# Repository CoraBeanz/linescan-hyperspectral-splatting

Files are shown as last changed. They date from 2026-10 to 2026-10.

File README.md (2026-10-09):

<p align="center">
  Line-Scan Hyperspectral 3D Gaussian Splatting. An SO-101 robot arm holds a spectrograph whose scan line sweeps across a potted plant; behind the line the plant turns into Gaussians, and one Gaussian's stored spectrum is shown in a callout.
</p>

<h3 align="center">A homebuilt pushbroom spectrograph rides a robot arm, and the 3D Gaussian splat it trains stores a full 500–950 nm spectrum in every Gaussian instead of an RGB color.</h3>

<p align="center">
  
  
  
  
  
  
</p>

<p align="center">
  <a href="#how-it-works"><b>How it works</b></a> ·
  <a href="#the-rig"><b>The rig</b></a> ·
  <a href="#cad-model"><b>CAD model</b></a> ·
  <a href="#optical-path"><b>Optical path</b></a> ·
  <a href="#optiland-model"><b>Optiland model</b></a> ·
  <a href="#software"><b>Software</b></a> ·
  <a href="#reconstruction"><b>Reconstruction</b></a> ·
  <a href="#roadmap"><b>Roadmap</b></a> ·
  <a href="docs/parts_list_and_design.md"><b>Parts list</b></a>
</p>

## How it works

A hyperspectral camera records a whole spectrum at every pixel instead of three color channels, which shows things RGB can't, like the sharp rise in a leaf's reflectance just past red. This one is built from M12 board lenses, grating film and a Raspberry Pi camera sensor, for under $500 in optics and scanner parts.

| 1 · Pick a viewpoint | 2 · Sweep the slit | 3 · Train the splat |
|---|---|---|
| The SO-101 arm carries the scanner head to a pose and holds still. An RGB camera on the head reads an AprilTag board to get that pose. | A NEMA 8 stepper turns the scan mirror one microstep per frame. Each frame is one line of the object by its spectrum, and about 150 lines cover a 63 × 42 mm patch. | Every scan line is a training sample. A C++/CUDA renderer draws the splat through a line-camera model at that line's pose and compares it with the measured line. |

## The rig

<p align="center">
  Side view of the setup: the SO-101 arm holds the scanner head above a potted plant on an AprilTag board, a scan mirror sweeps a line across the plant, halogen lamps light it, and a Jetson Nano and an ESP32 sit on the table. An inset shows the parts inside the scanner head.
</p>

<table>
  <tr>
    <td width="42%" valign="top">
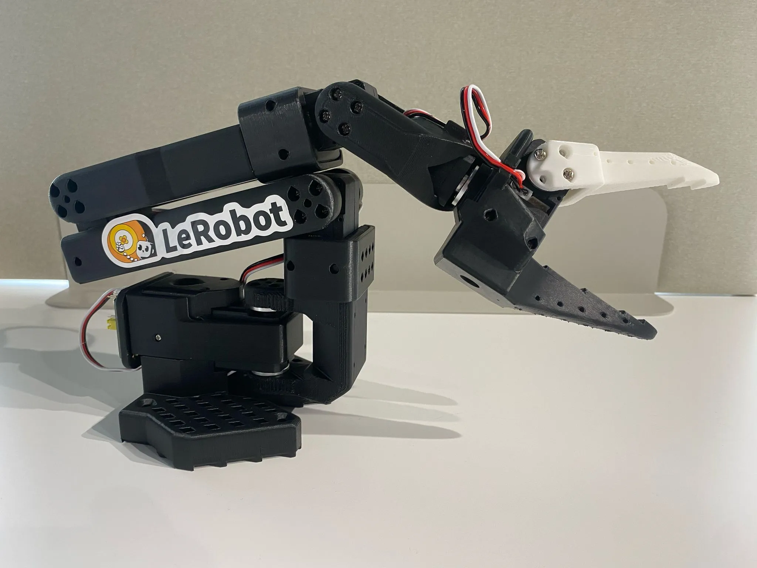
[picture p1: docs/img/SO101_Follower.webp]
Photo of an assembled SO-101 follower arm
      
      <br><sub>SO-101 follower arm. Photo: <a href="https://github.com/TheRobotStudio/SO-ARM100">TheRobotStudio/SO-ARM100</a>, Apache-2.0.</sub>
    </td>
    <td valign="top">

**Arm.** An [SO-101](https://huggingface.co/docs/lerobot/so101) follower from [LeRobot](https://github.com/huggingface/lerobot), with six STS3215 servos. It only sets the viewpoint, then holds still while the mirror scans.

**Scanner head.** The spectrograph below, plus a first-surface scan mirror on a 60 g NEMA 8 stepper. A TMC2209 driver runs it at 1/32 microstepping from an ESP32, which takes plain-text commands from the Jetson over USB serial.

**Pose.** An RGB camera on the head sees an AprilTag board under the object.

**Light.** Halogen lamps, because LEDs give almost nothing past 700 nm.

**Compute.** A Jetson Nano for capture, the calibration warp and the CUDA splat renderer.

  </td>
  </tr>
</table>

## CAD model

<p align="center">
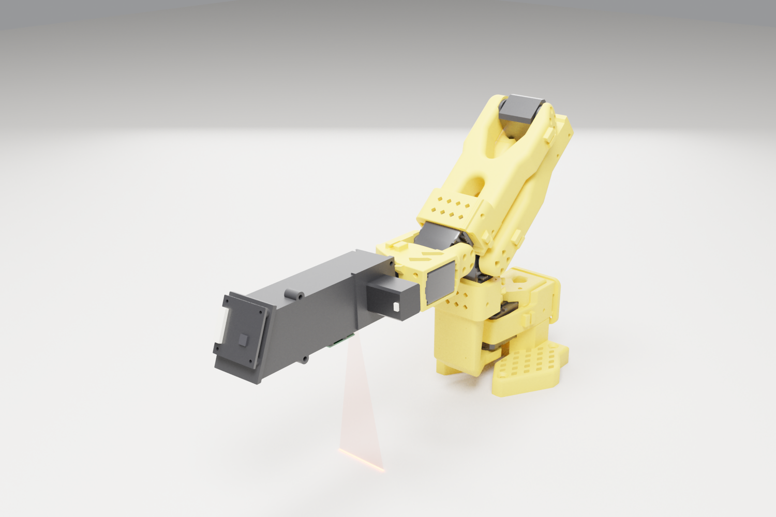
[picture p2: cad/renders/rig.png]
Render of the FreeCAD model: the SO-101 arm, folded, holds the black scanner head out over a table, and a faint red fan of light from the scan window draws a line on the table.
  
</p>

<table>
  <tr>
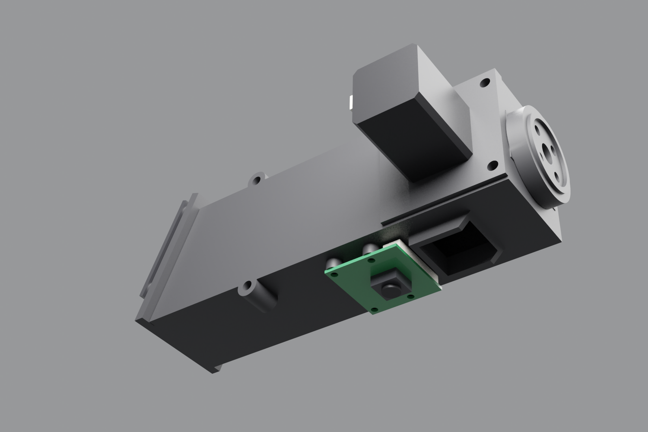
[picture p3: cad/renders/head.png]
The scanner head from below: the housing with its scan window and hood, the pose camera board, the NEMA 8 stepper on the lid and the round wrist puck.
    <td width="50%"></td>
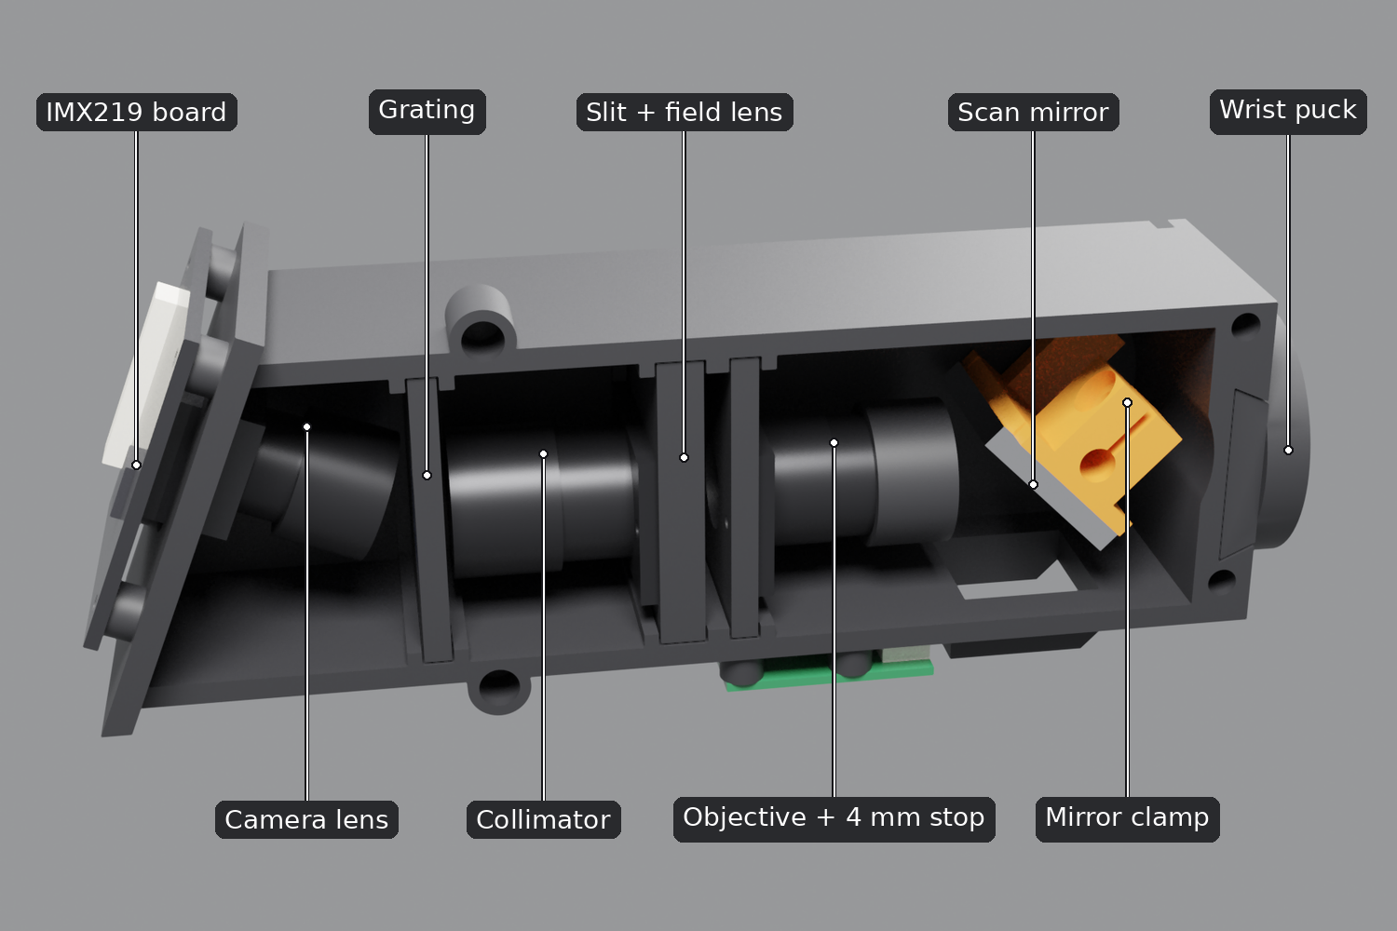
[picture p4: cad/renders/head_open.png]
The head with the lid and stepper hidden and the parts labelled: IMX219 board, camera lens, grating, collimator, slit and field lens, objective with its 4 mm stop, scan mirror on its clamp, and the wrist puck.
    <td width="50%"></td>
  </tr>
  <tr>
    <td><sub>The head from below: scan window and hood, pose camera, NEMA 8 stepper, wrist puck.</sub></td>
    <td><sub>Lid and stepper hidden to show the optical train.</sub></td>
  </tr>
</table>

The whole rig is a parametric [FreeCAD model](cad/). One script builds the SO-101 from its URDF, reads the optical spacings from the Optiland model, and wraps the optics in a printable PETG housing that slides onto a puck on the wrist-roll servo. It checks the parts for clashes, the mirror's full turn and the wrist's clearance, and works out the servo load: the 185 g head needs 74% of the shoulder servo's stall torque with the arm stretched out level, and 18% in the folded scanning pose above. The STLs and assembly steps are in [`cad/`](cad/).

## Optical path

<p align="center">
  Optical path, side view in the dispersion plane: light from one line of the object reflects off the scan mirror, passes a 500 nm long-pass filter and a 16 mm objective, focuses on a 50 micron slit with a field lens behind it, is collimated by a 25 mm lens, fanned out by a 500 lines per mm grating a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
</p>

A 16 mm f/4 objective images the object onto a 50 µm slit, so the instrument sees one line at a time. A field lens right behind the slit steers every point of that line toward the camera. A 25 mm lens, used backward, collimates the light, and a 500 lines/mm transmission grating fans it out by wavelength. A 12 mm f/2 lens, tilted 22° to the first diffraction order, refocuses the fan onto an IMX219 NoIR sensor, so each frame is one line of the object by its spectrum. A 500 nm long-pass filter in front keeps second-order light off the near-infrared end. Why each part is there: [final optical train](docs/parts_list_and_design.md#2-final-optical-train-config-c).

### What the camera sees

<p align="center">
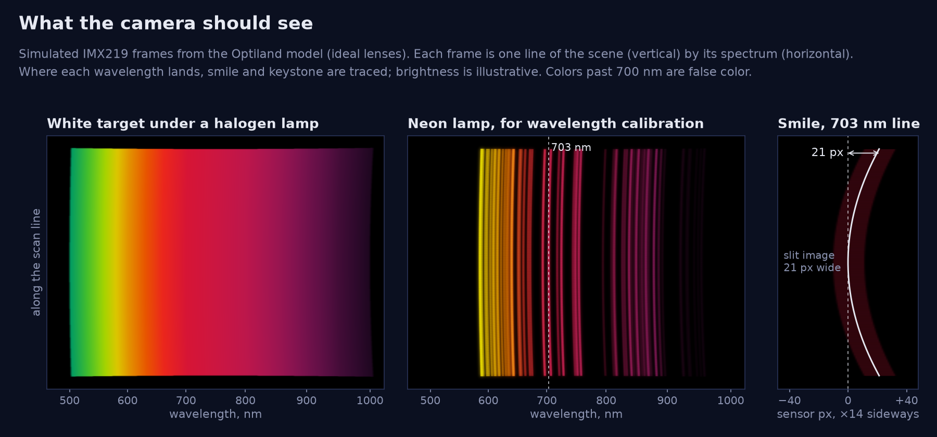
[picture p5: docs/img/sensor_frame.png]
Simulated IMX219 frames from the Optiland model: a white target under a halogen lamp shows a smooth band from green to near-infrared, a neon lamp shows curved emission lines, and a zoom shows the smile of the 703 nm neon line.
  
</p>

Each frame is the scan line (vertical) by its spectrum (horizontal), at about 5.8 px per nm. Spectral lines bow slightly across the frame (smile, up to about 33 px at the line ends) and the line length shifts a little with wavelength (keystone, about 11 px). Both get calibrated once with lamp lines and removed by a warp.

## Optiland model

[`optics/spectrograph_model.py`](optics/spectrograph_model.py) builds the whole train in [Optiland](https://github.com/HarrisonKramer/optiland) with ideal thin lenses and traces it. Tracing changed the design twice: the stock Pi NoIR lens was far too small to catch the collimated beam, and without a field lens most of the light from the ends of the line missed the camera lens.

<p align="center">
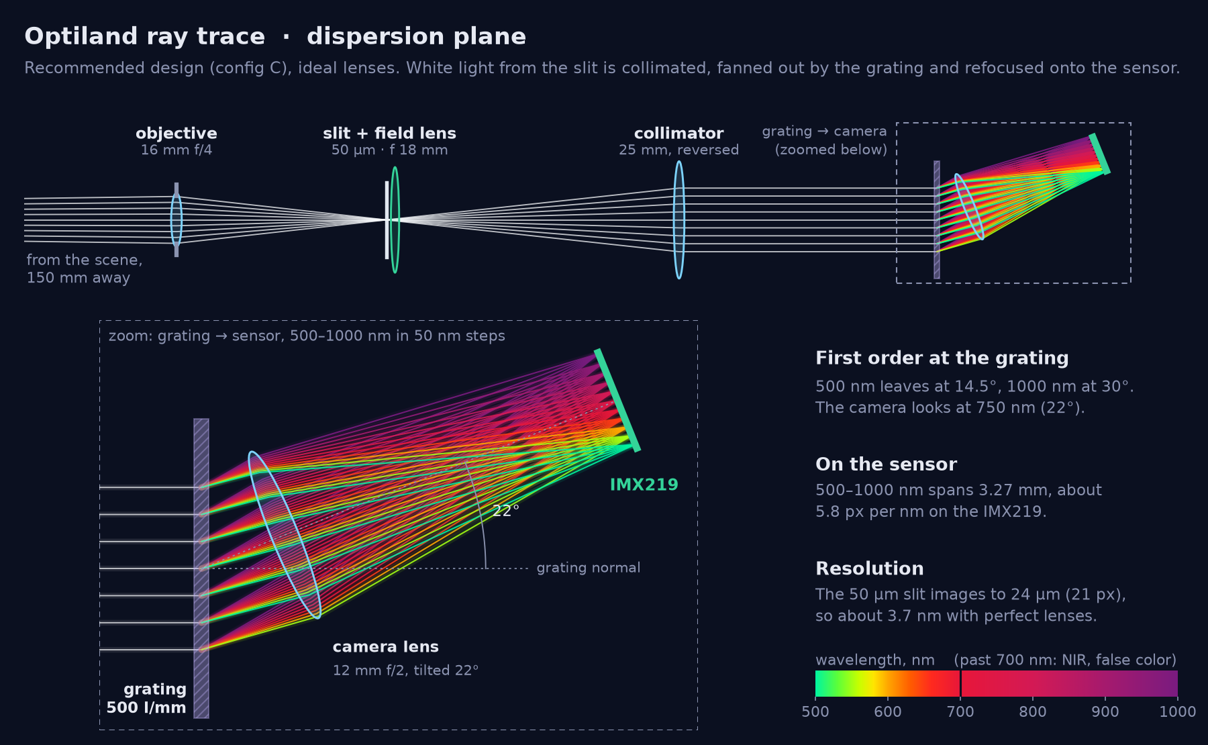
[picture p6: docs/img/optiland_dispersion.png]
Optiland ray trace of config C in the dispersion plane: white light from the slit is collimated, fanned out by the grating from 500 to 1000 nm and refocused onto the sensor by the camera lens tilted 22 degrees.
  
</p>

<p align="center">
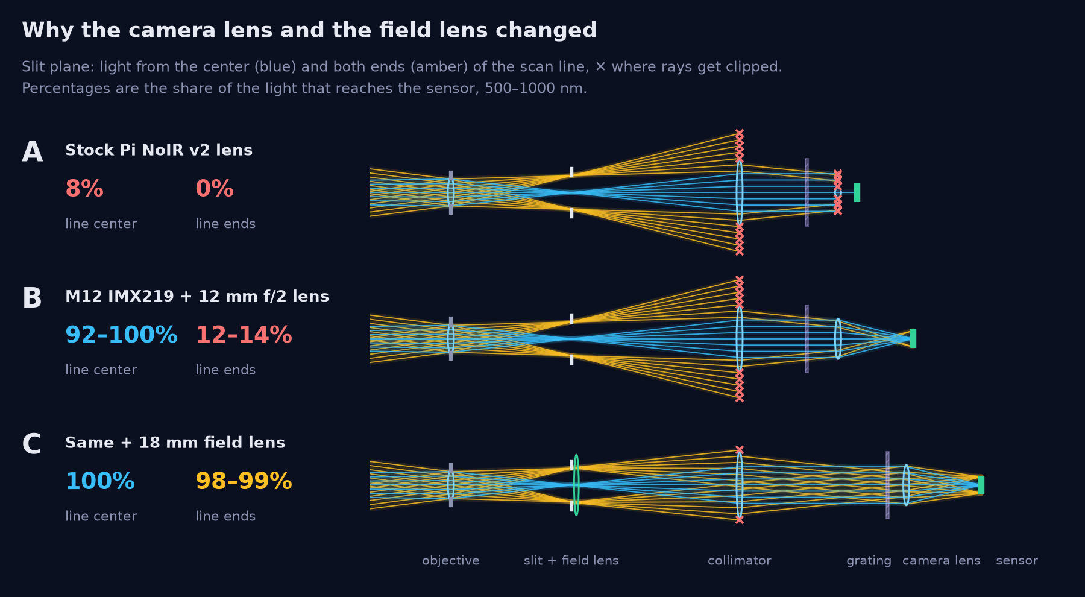
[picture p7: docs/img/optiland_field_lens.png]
Optiland traces of configs A, B and C in the slit plane. Light from the ends of the scan line gets clipped in A and B; with the field lens in C, 98 to 99 percent of it reaches the sensor.
  
</p>

| Config (ideal lenses) | Light at line center | Light at line ends | Dispersion | Spectral resolution | Pixels along the line |
|---|---|---|---|---|---|
| A: stock Pi NoIR v2 lens | 8% | 0% | 1.5 px/nm | 3.7 nm | 543 |
| B: M12 IMX219 + 12 mm f/2 lens | 92–100% | 12–14% | 5.8 px/nm | 3.7 nm | 2,143 |
| **C: B + 18 mm field lens** | **100%** | **98–99%** | **5.8 px/nm** | **4.1 nm** | **2,204** |

Resolution is geometric, with perfect lenses: the slit image's width over the dispersion. For A and B it is the paraxial estimate. For C it is traced through the grating, which widens the slit image 1.08× as the beam leaves at 22°, and the field lens adds 1.03×. The parts that were bought trace to 4.1 nm as [`cad/`](cad/README.md) builds the head, with the field lens curved side to the slit (config E); turned the other way it would be 5.4 nm (config D, [design notes](docs/parts_list_and_design.md#with-the-parts-that-were-bought-configs-d-and-e)). Real M12 lenses will likely land around 5–8 nm. More in the [modeling notes](docs/parts_list_and_design.md#5-modeling-notes-and-limits).

```bash
pip install optiland                   # tested with 0.6.2
python optics/spectrograph_model.py    # prints the table, writes optics/model_output/
python optics/readme_figures.py        # redraws the Optiland figures in docs/img/
```

Full output: [`optics/model_output/results.txt`](optics/model_output/results.txt) and the [ray layouts](optics/model_output/).

## Software

<p align="center">
  Block diagram of the code. The scan-mirror firmware on the ESP32 talks to the ROS 2 scan arm on the Jetson Nano over USB serial. The camera's frames go to the ROS 2 side during scans and to the calibration kit as lamp frames, and the calibration kit gives the ROS 2 side a wavelength map and a warp.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
</p>

The rig isn't built yet, so every module is written and tested against simulated hardware: the firmware on a simulated rig, the ROS 2 side on a fake servo bus and a simulated mirror, the calibration kit on lamp frames rendered through the Optiland model, and the splat on a synthetic scan with known poses. The [instrument simulator](sim/) ties them together: a digital twin of the whole rig that renders complete scan sessions, raw frames and logged poses, from a scene whose spectra and geometry are known. GitHub Actions runs each module's checks on every pull request that touches it.

| Module | What CI checks | Status |
|---|---|---|
| [Scan-mirror firmware](firmware/) | Unit tests on a simulated rig, again under AddressSanitizer and UndefinedBehaviorSanitizer, and the ESP32 build |  |
| [ROS 2 scan arm](ros2/) | `colcon build` and `colcon test` in a ROS 2 Humble container, up to a two-viewpoint scan on mock hardware |  |
| [Calibration kit](calibration/) | The self-test and unit tests on Python 3.10 and 3.13, and the Jetson's capture commands on Python 3.6 and numpy 1.13 against a stand-in camera |  |
| [Line-camera splat](splat/) | CPU build and unit tests, and a small synthetic scan trained end to end; the CUDA build with CUDA 13.4 for a desktop GPU (CI has no GPU, so the GPU tests skip there) |  |
| [Jetson Nano build](jetson/README.md) | The renderer and trainer built with the Nano's CUDA 10.2 and gcc 7.5 for sm_53, every kernel checked against the Nano's registers and shared memory, and the tests on arm64 Ubuntu 18.04 |  |
| [Splat viewer](viewer/) | The page's file reader, colour weights, spectra and WebGL2 image against the C++ renderer, then the page itself at a desktop and a phone size, in headless Chromium |  |
| [GitHub Pages site](https://corabeanz.github.io/linescan-hyperspectral-splatting/) | Builds the front page and the viewer, opens them in headless Chromium, and deploys them from `main` |  |
| [Instrument simulator](sim/) | The self-test, which scans a relief target, calibrates the simulated instrument and checks the reflectance against the truth, and the unit tests, on Python 3.10 with the oldest packages it allows and on 3.13 |  |
| [Virtual first light](pipeline/) | Nightly: a simulated scan through calibration, conversion, training, export and the viewer's reader, each hand-off checked against the simulator's truth |  |
| [CAD model](cad/) | Lint on the FreeCAD scripts |  |
| [PCBs](pcb/) | KiCad's ERC and DRC on the scan-mirror controller and hall-sensor boards, including the check that each board matches its schematic |  |
| [Optiland model](optics/) | Reruns the model and checks that its results, the CAD's as-built optics and the calibration kit's design map are current |  |
| README and docs | The diagrams match the scripts that draw them, and every relative link resolves |  |

Each module's README says how to build and test it locally, and its workflow in [`.github/workflows/`](.github/workflows/) runs the same commands.

### Scan-mirror firmware

<p align="center">
  Timing diagram of a stare scan. At each tick of a line clock, 33.3 ms apart at 30 frames per second, the ESP32 sends two step pulses 0.65 ms apart; the MOVING pin stays high until the mirror has been still for 3 ms, then the TRIG pin pulses and the line is reported ready. Each camera frame, a rolli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
</p>

An ESP32 runs the mirror from a 50 µs timer interrupt and keeps a line clock that follows the camera's frames. In a stare scan it steps the mirror at each tick, waits for it to settle, and holds it still through the frame; in a sweep scan it turns the mirror at a constant speed and reports its exact position at each tick. Every line, move and hall-sensor edge is stamped in ESP32 microseconds, so each camera frame can be matched to a mirror angle. Homing finds the middle of a hall sensor's window, which repeats to a microstep, and the TMC2209's current and microstepping are set over its UART, with a watchdog that stops the motor on a driver fault.

The Jetson talks to it in [plain-text lines over USB serial](firmware/PROTOCOL.md) rather than micro-ROS, as first planned: there's no agent to run, any serial monitor can drive it, and a ROS 2 node turns it into topics and services. Wiring, first power-up and a bench test with a logic analyser are in [`firmware/`](firmware/).

### ROS 2 scan arm

ROS 2 Humble runs in Docker on the Jetson Nano, since JetPack 4 is Ubuntu 18.04. A ros2_control driver runs the SO-101's STS3215 servos at 100 Hz. For each viewpoint in a plan, `scan_sweep` moves the arm, waits for it to stop, and asks the mirror bridge for a sweep. The bridge maps the ESP32's clock onto ROS time, so each line gets the arm's joint angles at the moment the mirror settled. Through the URDF, which takes the head's geometry from the CAD model, those give the head pose and the line-camera pose: one row per line in `lines.csv`. With mock servos and a simulated mirror the whole stack runs on any Linux machine with Docker, and Foxglove draws every scan line where it lands. The driver also stops the arm on a servo fault, a stall or an e-stop, and keeps the head off the table ([arm safety](ros2/README.md#arm-safety)). Setup on the Nano and first steps with the real arm: [`ros2/`](ros2/README.md).

### Calibration

<p align="center">
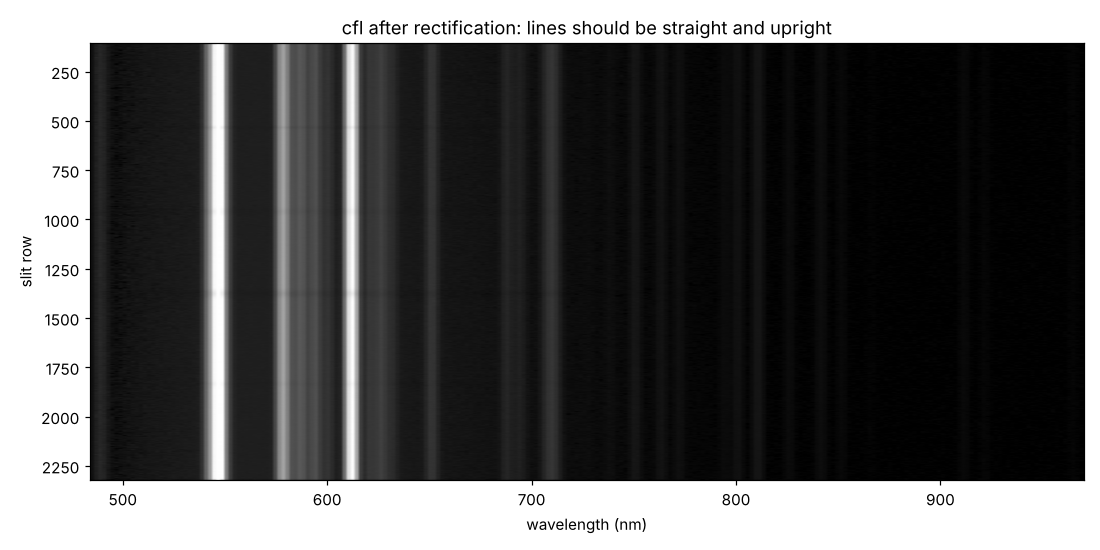
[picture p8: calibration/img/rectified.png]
A synthetic CFL frame after calibration: wavelength from 484 to 970 nm across, slit rows down; every lamp line is a straight vertical stripe.
  
  <br><sub>A synthetic CFL frame after calibration. On the sensor these lines bow by up to 35 px; here each one is a straight column at its own wavelength.</sub>
</p>

About ten minutes of lamp frames calibrate the spectrograph. A CFL bulb and a neon glow lamp give about 100 lines from 490 to 970 nm, a halogen lamp on PTFE gives the slit's ends and the spectral response, and a red laser pointer checks the result. The calibration kit, `hsical`, fits the wavelength of every pixel, the warp that straightens the bowed lines (smile) and evens out the slit's length across wavelengths (keystone), and the response that turns counts into radiance or reflectance, then writes a report with pass/fail checks. Its capture commands run on the Jetson's stock Python 3.6; the fitting runs on a PC. Before a scan, `hsical check` compares a quick CFL frame with the calibration and says whether anything has moved since.

Without the hardware, it is tested on sessions rendered through the Optiland model from a deliberately imperfect copy of the design: shifted on the sensor, with a denser grating, barrel distortion, dust on the slit, the sensor's colour mosaic and noise. At full resolution it recovers the truth to:

| Error against the truth | Result | Limit |
|---|---|---|
| Wavelength of every pixel, rms | 0.020 nm | 0.10 nm |
| Wavelength of every pixel, worst | 0.070 nm | 0.30 nm |
| Laser wavelength | 0.003 nm | 0.20 nm |
| Reflectance of a test scene, rms | 0.8% | 3% |

First light step by step, and how each fit works: [`calibration/`](calibration/).
Where the head's cameras and mirror really sit on the wrist, measured from one scan of a printed tag board: [`calibration/headcal/`](calibration/headcal/README.md).

### Instrument simulator

<p align="center">
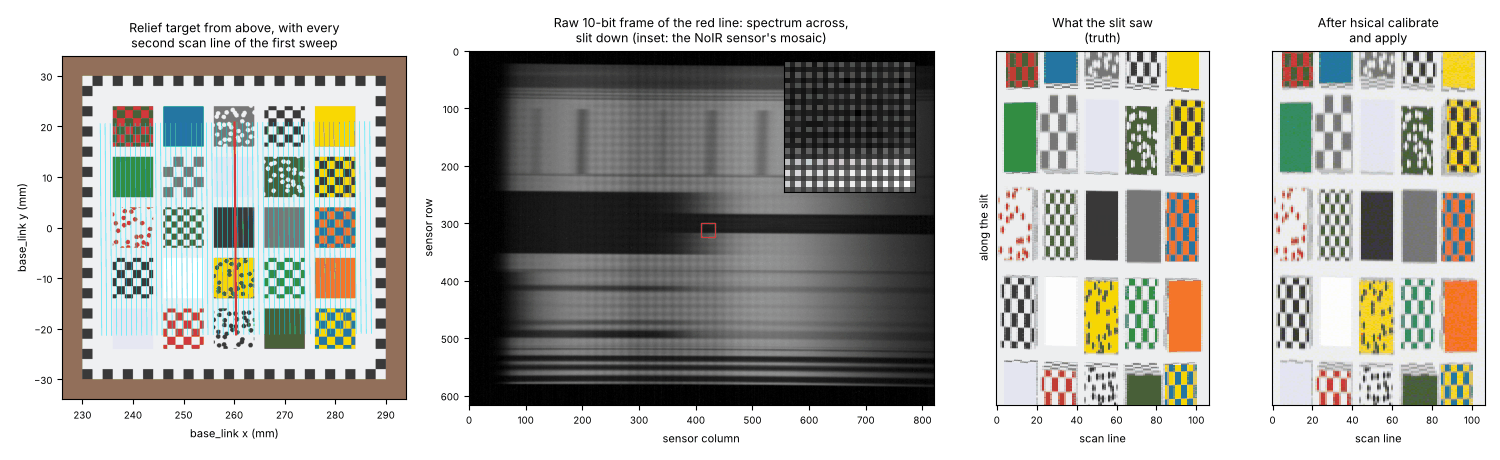
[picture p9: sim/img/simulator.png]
Four panels from the simulator. The relief target from above: a 5 by 5 block of coloured and patterned pillars inside a checker border, with the first sweep's scan lines drawn across it. A raw sensor frame of one line: a grey band of spectrum with dark absorption bars and horizontal stripes where t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
  
  <br><sub>The relief target with every second line of the first sweep, the raw frame of the red line, and the whole sweep as the slit really saw it next to what the calibration kit made of the raw frames.</sub>
</p>

The [simulator](sim/) is a digital twin of the whole scanner: the arm, the scan mirror, the objective and slit, the spectrograph and its camera. Given a scene with known spectra and a scan plan, it renders the raw frame of every scan line and writes a complete session in the rig's own format, with the arm's servo offsets, flex and encoder steps and the mirror's homing error in the log, as the real rig's will have them. Most of it is the repo's own code, imported rather than copied: the URDF's kinematics from the ROS 2 package, the synthetic spectrograph from the calibration kit, and the Optiland design map. Its self-test calibrates the simulated instrument, turns two sweeps of a relief target into reflectance and checks them against the truth: 1.6% RMS reflectance error, and the absorption bands of a rare-earth tile within 0.07 nm.

### On the Jetson Nano

The Nano is stuck on JetPack 4.6: Ubuntu 18.04, CUDA 10.2 and gcc 7. [`jetson/`](jetson/README.md) builds splat for its GPU in a container that uses JetPack's own CUDA, and builds the ROS 2 image in a way JetPack's old Docker can manage. A day-one script builds and tests both and times training on the GPU. From a PC, the same scripts build splat with the Nano's compilers, check that every kernel fits the Nano's registers and shared memory, and run the tests on arm64 Ubuntu 18.04. What training needs on the Nano, in memory and time per dataset, and the commands that measure it: [`splat/docs/nano_budget.md`](splat/docs/nano_budget.md).

## Reconstruction

Published hyperspectral splatting, such as [HyperGS](https://openaccess.thecvf.com/content/CVPR2025/papers/Thirgood_HyperGS_Hyperspectral_3D_Gaussian_Splatting_CVPR_2025_paper.pdf) and [DD-HGS](https://arxiv.org/abs/2505.21890), trains on full multi-view hyperspectral images. Here the splat trains straight from raw scan lines, through a model of the instrument itself.

- **Spectral Gaussians.** Each Gaussian keeps the usual position, shape and opacity, and stores a spectrum over 500–950 nm where a normal splat stores RGB.
- **A line camera, not a pinhole.** The slit only sees a thin fan of rays, and the mirror angle tilts that fan. For each scan line, the renderer draws the splat along that one fan and compares the resulting line of spectra with the measured line.
- **Poses get refined too.** The arm and the tag board give each viewpoint a pose, and the optimizer can adjust those poses along with the Gaussians, so small arm errors don't blur the result.
- **Calibrated input.** Neon and CFL lamp lines fix the wavelength scale, the warp removes smile and keystone, and a white PTFE reference turns counts into reflectance.

Splatting through a non-pinhole camera has precedent in satellite imagery ([RPC-GS](https://arxiv.org/abs/2606.06690)), and close-range pushbroom cameras have been calibrated for plant phenotyping ([Behmann et al. 2015](https://doi.org/10.1016/j.isprsjprs.2015.05.010)). This project puts the two together on hobby hardware.

### Training on a synthetic scan

The renderer and trainer in [`splat/`](splat/) are C++17, with a CUDA rasterizer written for the Nano's CUDA 10.2 and a CPU reference that the tests hold it to. Until there are real scans, they train on a synthetic one: a board with paint patches, a hidden word that only shows past 740 nm, a leaf-green ball and an orange box, scanned through the head's mirror geometry from the CAD model. Each sweep's head pose is off by about 1 mm and 0.3° per axis, as the arm's will be.

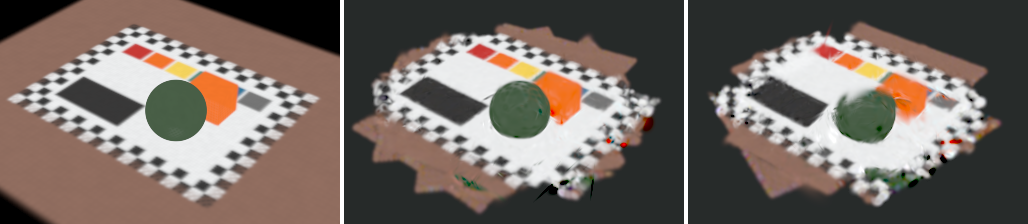
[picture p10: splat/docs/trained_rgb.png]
Three views of the scene from the overview camera: the true scene, a splat trained from 16 sweeps that matches it closely, and one trained from 8 sweeps, where the ball smears into the board and the checker border doubles.


The true scene (left), and splats trained from 16 sweeps (middle) and from 8 (right). From 16 sweeps the trainer cuts the pose error from 10.9 px to 0.97 px at 256 px per line, which lines the sweeps up to about 0.15 mm on the board, and it renders the measured lines down to their noise. That takes 16 s on a desktop RTX 4070 SUPER, or under two minutes on a 4-core CPU. From 8 sweeps the ball and the box are seen from too few directions and get painted onto the board, so the rig will scan many sweeps from all around. The model, the CUDA passes and more results are in [`splat/`](splat/).

### In the browser

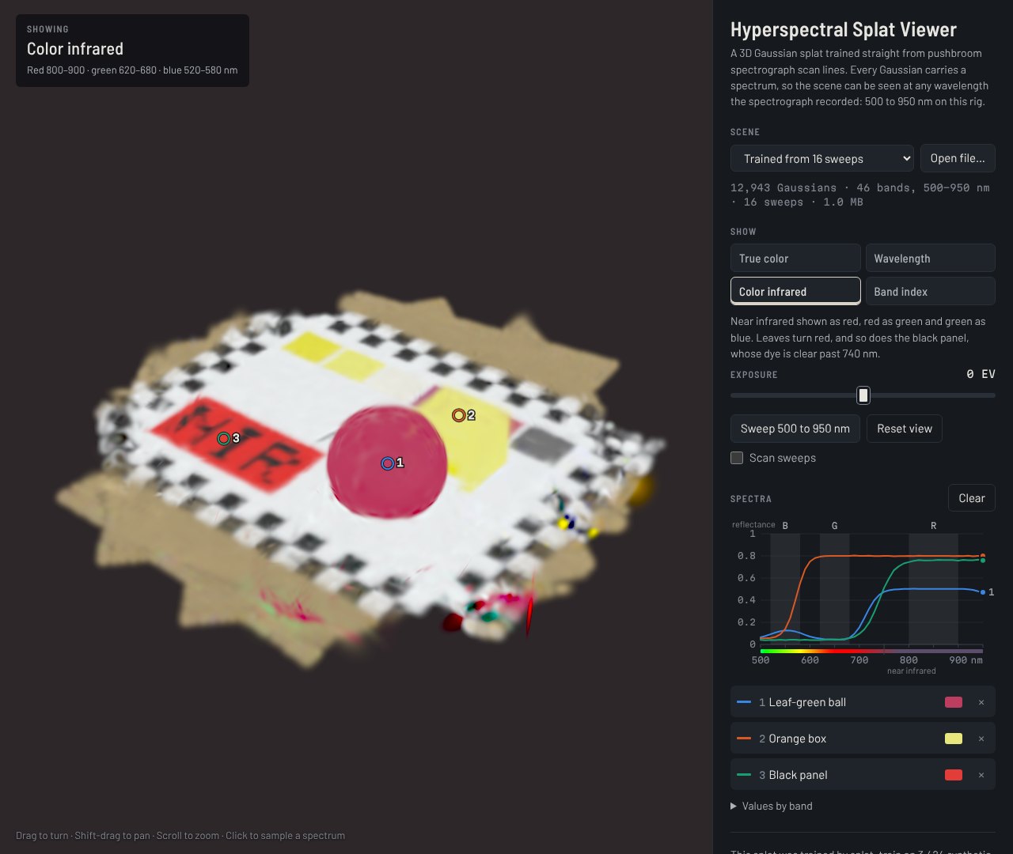
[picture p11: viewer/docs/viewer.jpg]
The viewer in color infrared: the splat trained from 16 synthetic sweeps, where the green ball and the black panel's hidden word NIR show red, beside the controls and a chart of the spectra sampled at the ball, the box and the panel.


Every Gaussian carries a spectrum, so the [viewer](viewer/) can draw a trained splat at any single wavelength, in true color, in color infrared, or as a band index such as NDVI, and it plots the full spectrum of any point you click. Above, in color infrared, the ball's leaf spectrum and the black panel's dye both rise past 700 nm, so both turn red and the hidden word shows. It is plain HTML, JavaScript and WebGL2 with no build step, and its tests check it against the C++ renderer. **[Open it in your browser](https://corabeanz.github.io/linescan-hyperspectral-splatting/viewer/)**, on GitHub Pages.

It also shows what each part of the scene is made of: [`splat_materials`](splat/README.md#material-maps) labels every Gaussian by spectral angle against a library of spectra, clusters them and unmixes them, and on the trained splat 97% of the map's pixels get the right material.

## Roadmap

- [x] First-order optical design and Optiland model (configs A, B, C, and D and E with the parts bought)
- [x] [FreeCAD model](cad/) of the arm and scanner head, with printable housing, optics carriers and wrist mount
- [x] [Software](#software), tested in CI against simulated hardware: scan-mirror firmware, ROS 2 scan arm, calibration kit, line-camera splat renderer and trainer, browser viewer, the Jetson Nano build and an instrument simulator
- [ ] **Bench spectrometer:** slit, field lens, collimator, grating and camera aimed at neon and CFL lamps; fit the wavelength map and the smile/keystone warp with the [calibration kit](calibration/)
- [ ] **Line imager:** add the objective, focus it on a printed target, measure the line on a knife edge
- [ ] **Scanner:** add the mirror and stepper, scan a color card, assemble the datacube on the Jetson (first CUDA kernel: warp + bin)
- [ ] **3D:** arm viewpoints and AprilTag poses, then the first splat trained on real scans

Details for each step are in the [build order](docs/parts_list_and_design.md#4-build-order).

## Stack

| Layer | Built with |
|---|---|
| **Optics** | Python and [Optiland](https://github.com/HarrisonKramer/optiland): ideal-lens model now, catalog lenses next |
| **CAD** | [FreeCAD](https://www.freecad.org/), scripted in Python around the SO-101's URDF |
| **Firmware** | C++ on an ESP32 (Arduino core, PlatformIO) driving a TMC2209, with Unity tests on a simulated rig |
| **Robotics** | ROS 2 Humble in Docker on the Jetson Nano: a ros2_control driver for the STS3215 servos, the URDF and the scan sweeps |
| **Capture and calibration** | Python, numpy and scipy; raw 10-bit frames from the IMX219 NoIR on the Jetson Nano's CSI port, through V4L2 |
| **Reconstruction** | C++17 and CUDA: line-camera Gaussian splat renderer and trainer for the Jetson Nano |
| **Viewer** | Plain HTML, JavaScript and WebGL2, tested in headless Chromium with Playwright |
| **Simulation** | Python and numpy, reusing the calibration kit's and the ROS 2 packages' own code |
| **CI** | GitHub Actions, a workflow per module |

## Repo map

```
docs/
├── parts_list_and_design.md   parts with vendors and prices, first-order design, build order
├── optical_train_v2.svg       optical train drawing (v1 kept alongside)
├── img/                       README figures; img/src/ holds the scripts that draw the SVGs
└── site/                      the GitHub Pages front page, and the script that builds the site
optics/
├── spectrograph_model.py      Optiland model of the spectrograph, configs A–E
├── readme_figures.py          traces the model and renders the Optiland figures
└── model_output/              results.txt and ray layouts
cad/
├── so101_hsi_rig.FCStd        FreeCAD assembly: SO-101 arm and scanner head
├── build_rig.py               builds it, checks clearances and servo load, exports
└── stl/, step/, renders/      printable parts, the head as STEP, images
firmware/
├── lib/scanmirror/            step generator, line clock, commands, homing: plain C++
├── src/main.cpp               the ESP32 glue
├── test/                      Unity tests on a simulated rig
└── PROTOCOL.md                the serial protocol
ros2/
├── so101_scan_*/              ROS 2 Humble packages: driver, URDF, bringup, sweeps, messages
└── docker/, udev/             the container for the Jetson Nano, stable device names
calibration/
├── hsical/                    capture, calibration, reports: python -m hsical
└── tests/                     pytest on synthetic sessions
splat/
├── include/, src/             line-camera renderer (CPU and CUDA) and trainer
├── tools/                     splat_synth, splat_train, splat_render, splat_export
└── tests/                     unit tests; the CUDA ones skip without a GPU
viewer/
├── index.html, js/            the browser viewer: WebGL2, no build step
├── data/                      two splats from the synthetic scan
└── test/                      checks against the C++ renderer, run in headless Chromium
sim/
├── hsisim/                    the instrument simulator: python -m hsisim
└── tests/                     pytest, up to a scan calibrated end to end
jetson/
├── build_all.sh, splat.sh     the Nano's day-one build, splat in its container
├── ros.sh                     the ROS 2 image on JetPack 4.6's Docker
└── check.sh                   the same builds from a PC, with the Nano's compilers
.github/workflows/             CI, a workflow per module
```

## Background reading

- Kerbl et al., [3D Gaussian Splatting for Real-Time Radiance Field Rendering](https://repo-sam.inria.fr/fungraph/3d-gaussian-splatting/), ACM TOG (SIGGRAPH) 2023. [arXiv:2308.04079](https://arxiv.org/abs/2308.04079)
- Thirgood et al., [HyperGS: Hyperspectral 3D Gaussian Splatting](https://openaccess.thecvf.com/content/CVPR2025/papers/Thirgood_HyperGS_Hyperspectral_3D_Gaussian_Splatting_CVPR_2025_paper.pdf), CVPR 2025
- Narayanan et al., [Diffusion-Denoised Hyperspectral Gaussian Splatting](https://arxiv.org/abs/2505.21890) (first posted as *Hyperspectral Gaussian Splatting*), arXiv 2025
- Wagner et al., [RPC-GS: Gaussian Splatting with native RPC Rendering for Satellite Imagery](https://arxiv.org/abs/2606.06690), arXiv 2026
- Behmann et al., [Calibration of hyperspectral close-range pushbroom cameras for plant phenotyping](https://doi.org/10.1016/j.isprsjprs.2015.05.010), ISPRS Journal of Photogrammetry and Remote Sensing 106, 2015

## Credits

- SO-101 photo: [TheRobotStudio/SO-ARM100](https://github.com/TheRobotStudio/SO-ARM100) (`media/SO101_Follower.webp`), used unmodified under the Apache License 2.0; a copy of the license is in [`docs/img/SO-ARM100_LICENSE.txt`](docs/img/SO-ARM100_LICENSE.txt). The SO-101 is designed by The Robot Studio in collaboration with Hugging Face.
- SO-101 URDF and meshes in the CAD model: [TheRobotStudio/SO-ARM100](https://github.com/TheRobotStudio/SO-ARM100) (`Simulation/SO101`), Apache License 2.0.
- Ray tracing: [Optiland](https://github.com/HarrisonKramer/optiland) (MIT).

## License

The code, the CAD model and the docs are under the [MIT License](LICENSE). The SO-101's URDF and meshes (and their decimated copies in the CAD model) and the SO-101 photo are TheRobotStudio's, under the Apache License 2.0, as listed in [Credits](#credits).

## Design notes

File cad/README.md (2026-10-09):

# CAD: the SO-101 with the scanner head

<p align="center">
  Render of the SO-101 arm holding the black scanner head over a table, with a red fan of light from the scan window drawing a line on the table.
</p>

A parametric FreeCAD model of the whole rig: the SO-101 follower arm, the spectrograph head with every bought part in place, the 3D-printed housing that holds them on the optical axis of [layout E](../optics/spectrograph_model.py) (the optics model of the parts that were bought), and a puck that bolts the head to the wrist-roll servo where the gripper used to be. A printed tray holds the scan-mirror controller board from [`pcb/`](../pcb/README.md) on the table behind the arm. One script builds it from a spreadsheet of numbers, checks it, and exports the STLs to print.

<table>
  <tr>
    <td width="50%">The head from below: scan window with its hood, pose camera board, stepper on the lid, and the round wrist puck.</td>
    <td width="50%">The head with the lid and stepper hidden and the parts labelled: scan mirror on its clamp, objective, slit and field lens, collimator, grating, tilted camera lens and the IMX219 board.</td>
  </tr>
  <tr>
    <td><sub>From below: scan window and hood, pose camera, stepper on the lid, wrist puck.</sub></td>
    <td><sub>Lid and stepper hidden.</sub></td>
  </tr>
</table>

## At a glance

- **Head:** 187 g and 64 × 53 × 136 mm, wrist puck included. The NEMA 8 stepper is 60 g of that.
- **Printed:** nine parts on the head, about 68 g of PETG, plus the controller tray (30 g), an optional bench mount and a spare stop washer.
- **Checks:** no parts overlap. The mirror turns a full circle with at least 0.5 mm to spare. The head clears the wrist at every roll angle (1.4 mm closest) and through ±95° of wrist flex.
- **Watch out:** with the arm stretched out level, the shoulder servo has to hold 1.21 N·m, which is 75% of its stall torque. The stock gripper needs 0.86 N·m there. The scanning pose in the render needs only 0.30 N·m. See [Arm load](#arm-load).

## Files

```
cad/
├── so101_hsi_rig.FCStd     the assembly, driven by its Params spreadsheet
├── build_rig.py            builds the .FCStd from scratch, runs the checks, writes everything below
├── build_report.json       mass budget, servo torques, clearances, optical stations
├── stl/                    printed parts, already turned to their print orientation
├── step/hsi_head.step      the head with every part, for other CAD tools
├── optics_check.py         traces the as-built spacings with the Optiland model
├── optics_as_built.txt     its output
├── renders/                the images on this page
├── render/                 Blender render script and the labelling step
├── rig/                    the model: parameters, printed parts, bought parts, arm, statics
└── vendor/so101/           SO-101 URDF and a script that downloads its meshes
```

## How the head works

The head has its own frame: the origin is on the face of the wrist-roll horn, +Z points out along the roll axis, +Y faces the scene, and X runs along the slit and the mirror shaft.

**Light path.** Light comes in through the scan window on the +Y face and hits the mirror at 45°. It then goes through the filter cap (a 495 nm long-pass disc, then a thin washer whose 4 mm hole is the stop), the objective, the slit with the field lens right behind it, curved side first, the reversed collimator and the grating film. The camera lens, tilted 22°, focuses it onto the IMX219.

**Mount.** The wrist puck replaces the gripper on the wrist-roll horn. A dovetail rail on the puck runs along X, and the slot in the housing floor is open on the −X side, so the housing slides onto the rail from there until it stops against the closed end. The lid closes the −X side and the end of the slot with it, so the lid screws are what hold the head on.

**Optics carriers.** The objective carrier, slit block and grating carrier are plates that slide into rib slots from the open side. That lets you build and align the optics before the lid goes on. The bench puck has the same rail on a 50 × 40 mm plate with a 1/4"-20 nut, so the head can sit on a tripod or the optics table for the bench steps in the [build order](../docs/parts_list_and_design.md#4-build-order).

**Scan mirror.** A printed clamp grips the stepper's 4 mm shaft with an M3 pinch screw and holds the mirror on a flat pad parallel to the shaft. The pad is drawn for a 20 × 20 mm piece cut from a 3 mm front-surface mirror sheet, and notches in its edges mark where the mirror's ends go so it sits centred on the optical axis. Along the shaft the piece can be anything from 20 to 25 mm. Across the shaft keep it at 20 mm or a little under, because its corners pass 0.9 mm from the housing as it turns. For thinner glass, set `mirror_t` and rebuild, or glue the mirror onto a printed shim that makes up the difference to 3 mm. A 5 × 1.6 mm magnet in the clamp's tab passes an A3144 hall sensor in the +X wall when the mirror is turned 40° back from its 45° working angle, which gives each scan a home position. The sensor's leads leave the bottom of its body, bend out through a slot under its pocket, and pass through the [hall breakout](../pcb/README.md#hall-sensor-breakout), which is screwed flat on the outside with one M2 × 5.

**Camera.** The B0152 board sits outside the end wall on four standoffs. The CIL122 goes in the board's own M12 holder, which reaches through a 21 mm hole in the wall. The hole is sized from `brd_holder_w` so a square holder passes at any angle. Turn the board so the sensor's long side runs across the slit, since that is the axis the spectrum spreads along. Black tape around the board edge keeps light out of the end.

**Pose camera.** The Pi NoIR v2 sits on four standoffs on the +Y face next to the scan window, looking at the scene.

## Parts

### Printed

Print the housing, lid and carriers in black PETG. PETG holds up to the stepper's heat, which PLA may not, and black keeps stray light down. The STLs are already turned to the orientation below.

| Part | File | How to print | Mass |
|---|---|---|---|
| Housing | [`housing.stl`](stl/housing.stl) | Floor (dovetail side) on the bed, camera end up. 0.2 mm layers, 3 perimeters, 20% gyroid, supports only under the camera flange | 37 g |
| Lid | [`lid.stl`](stl/lid.stl) | Inner (flat) face on the bed. 4 perimeters around the motor holes | 13 g |
| Mirror clamp | [`mirror_clamp.stl`](stl/mirror_clamp.stl) | Mirror pad face down. 0.15 mm layers, 100% infill | 2 g |
| Wrist puck | [`wrist_puck.stl`](stl/wrist_puck.stl) | Horn side down (it bridges the 20 mm horn recess). 100% infill | 5 g |
| Objective carrier | [`objective_carrier.stl`](stl/objective_carrier.stl) | Flat | 2 g |
| Slit block | [`slit_block.stl`](stl/slit_block.stl) | Back face down so the blade recess prints flat. 0.12 mm layers | 4 g |
| Grating carrier | [`grating_carrier.stl`](stl/grating_carrier.stl) | Flat, film recess up | 2 g |
| Filter cap | [`filter_cap.stl`](stl/filter_cap.stl) | Lip face down. Check that the sleeve is a snug push fit on the objective | 1 g |
| Stop washer, 4 mm | [`stop_washer.stl`](stl/stop_washer.stl) | Flat, 0.2 mm layers. Clear any stringing from the hole, since its edge is the stop | 0.1 g |
| Stop washer, 5 mm (optional) | [`stop_washer_5mm.stl`](stl/stop_washer_5mm.stl) | As the 4 mm one. Swap it in at first light to compare: see [Optics as built](#optics-as-built) | 0.1 g |
| Bench puck (optional) | [`bench_puck.stl`](stl/bench_puck.stl) | Flat side down. A 1/4"-20 hex nut presses in from below | 19 g |
| Controller tray | [`controller_tray.stl`](stl/controller_tray.stl) | Floor on the bed. 3 perimeters, 20% infill. It stays on the table, so PLA is fine: see [Controller tray](#controller-tray) | 30 g |

### Bought

| Part | In the model |
|---|---|
| Objective: Commonlands CIL161, 15.6 mm, stopped to f/3.9 by the 4 mm washer | barrel size estimated |
| Collimator: Arducam LN016, 25 mm, used backwards | size from the listing, back focus estimated |
| Camera lens: Commonlands CIL122, 12 mm f/2 | barrel size estimated |
| Camera: Arducam B0152 IMX219 NoIR, M12 mount | 36 × 36 mm from the listing; holes, thickness and holder estimated |
| 2× M12 holder, uxcell, 20 mm screw spacing (objective, collimator), each cut down to 10 mm: see [Assembly](#assembly) | 24 × 17 × 14 mm from the listing; ear thickness estimated |
| Field lens: Edmund #49-840, 12.7 mm plano-convex, f = 15 mm, uncoated | datasheet |
| Slit: two 20 mm pieces of a 9 mm snap-off blade, set 50 µm apart with a feeler gauge | single-edge blades (38 × 19 mm) don't fit inside the head |
| Grating: 15 × 15 mm piece of 500 l/mm film, grooves along X | |
| Long-pass filter: Edmund #54-652, SCHOTT GG-495, Ø12.5 × 3 mm | listing. The cap's seat takes the ±0.38 mm diameter tolerance |
| Scan mirror: 20 × 20 mm piece cut from a RUEHALF 100 × 100 × 3 mm front-surface mirror | thickness from the listing |
| Stepper: StepperOnline 8HS11-0204S, NEMA 8, 1.8°, 0.2 A | size, shaft and holes from the listing; boss and thread depth estimated |
| A3144 hall sensor and a 5 × 1.6 mm magnet, magnetized through its thickness | measured |
| Hall breakout from [`pcb/`](../pcb/README.md#hall-sensor-breakout), 14 × 12.4 × 0.8 mm, with its 3-wire cable soldered in | outline, holes and lead positions from `pcb/` |
| Pose camera: Pi NoIR v2 (owned) | Raspberry Pi drawing |

### Hardware

| Qty | Part | Where |
|---|---|---|
| 4 | M3 × 6 | puck to the servo horn |
| 4 | M2 × 4 | stepper to the lid, from inside (the heads sit flush) |
| 2 + 2 + 2 | M3 × 35, M3 washers and M3 nuts | from the counterbores on the +X face, through the floor and the lid, nutted on the lid's motor pad |
| 2 + 2 | M3 × 8 and M3 × 6 heat-set inserts (Pofsnnx: 5.0 mm knurl, 4.5 mm holes) | lid ears to the housing |
| 1 + 1 | M3 × 8 and M3 nut | mirror clamp pinch screw |
| 8 + 8 | M2 × 5 and M2 × 4 heat-set inserts (Pofsnnx: 3.0 mm knurl, 2.85 mm holes) | camera board (4) and pose camera (4) |
| 2 | M2 × 5 | objective's M12 holder to its carrier, self-tapping into the printed pilot holes |
| 2 | M2 × 5 | collimator's M12 holder to the back of the slit block, self-tapping (3 mm of thread in the block) |
| 1 | M2 × 5 | hall breakout to the +X wall, self-tapping (2.5 mm of thread in the wall) |
| 4 + 4 | M3 × 6 and M3 heat-set inserts | controller board to its tray |
| 2 + 2 | 1/4"-20 or M6 screws, to suit the table, and washers | tray to the optical table |

Plus CA glue for the magnet, mirror and slit blades, and Kapton tape for the grating film. The [NEMA 17 build](#the-nema-17-option) holds its motor with two M3 × 6 instead, and the long bolts thread into the motor rather than into nuts.

## Measure these first

These numbers came from estimates or listings, not datasheets. Check them when the parts arrive, before printing the part they affect. All of them are cells in the Params sheet; the estimates are marked `est`.

| Value | Assumed | Affects |
|---|---|---|
| B0152 hole spacing (`brd_hole` along X, `brd_hole_y` along the dispersion) | 29 mm square | camera standoffs on the housing |
| B0152 lens holder size (`brd_holder_h`, `brd_holder_w`) | 10 mm tall, 14 mm square | camera opening in the end wall |
| B0152 sensor above the PCB (`sensor_above_pcb`) and PCB thickness (`brd_t`) | 1 mm, 1.6 mm | where the end wall sits so the sensor is in focus; camera screw length |
| CIL161 barrel (`obj_od`, `obj_len`), on the M12ANIR version | Ø14 × 18.5 mm | filter cap fit, objective position, and where the stop washer sits: 8.5 mm ahead of the lens's principal plane as drawn, 8.1 mm in layout E |
| CIL122 barrel (`cam_od`, `cam_len`), on the M12ANIR version | Ø15 × 19 mm | how close the camera lens can get to the grating |
| LN016 length (`coll_len`) | 21 mm | grating carrier position |
| Lens back focal lengths (`*_bfl`) | 5–6 mm | carrier positions. Turning a lens in its M12 thread takes up a millimetre or two |
| LN016 back focus (`coll_bfl`): rear of the barrel to the sharp image of a distant lamp | 6.0 mm; a sibling Arducam 25 mm lens lists 5.2 | slit block thickness, which puts the collimator where it focuses on the slit |
| CIL122 aperture: its spec table says f/2.0, the text on the same page f/2.4 | f/2.0, a 6 mm pupil | not the CAD. At f/2.4 (5 mm) the ends of the band lose a little more light; set `d_cam` to 5 in [`spectrograph_model.py`](../optics/spectrograph_model.py) and rerun `optics_check.py` to see how much |
| Lens thread lengths (`obj_thread`, `coll_thread`): rear end to where the barrel widens | 9 mm | where to cut the M12 holders, see [Assembly](#assembly) |
| M12 holder ear thickness (`h12_ear_t`) | 2 mm | holder screw length: M2 × 5 leaves 3 mm of thread in the carrier |
| Snap-off blade thickness (`blade_t`) | 0.38 mm | depth of the blade recess in the slit block |
| Stepper pilot boss (`mot_boss_d`, `mot_boss_h`) | Ø15 × 1.5 mm | the pocket in the lid it sits in; the motor has to sit flat on the pad |
| Stepper thread depth (`mot_hole_depth`) | 2.5 mm | the M2 × 4 screws reach 2.2 mm into it. M2 × 5 reach 3.2 mm, so use them only if the holes are that deep, or file 1 mm off them |

## Assembly

1. Cut two of the uxcell M12 holders down to 10 mm, the lens thread plus 1 mm. Cut from the end the lens screws into, not the ear end, and square the cut on sandpaper. A lens screwed in until its barrel stops against the cut end then has its rear end 1 mm inside the holder, where the model puts it. If a lens's thread isn't 9 mm, cut its holder to the thread plus 1 mm; with 13 mm of thread or more, leave the holder whole. Then score and snap a 20 × 20 mm piece from the mirror sheet, scoring the bare back so the coated face isn't scratched.
2. Press in the heat-set inserts: two M3 in the lid bosses on the housing, four M2 in the camera standoffs and four M2 in the pose-camera standoffs.
3. Build the optics on their carriers. The objective's holder screws to the objective carrier. Drop the long-pass disc into the filter cap and the 4 mm stop washer in on top of it, then push the cap onto the front of the lens until the lens presses them together. In the slit block, the field lens drops into its pocket from the front, curved side up toward the blades, and its flat face sits on the ledge at the bottom of the pocket (a dot of glue on its rim stops it rattling). Turned the other way it would make the slit look 1.35× as wide, and the resolution would drop from 4.1 to 5.4 nm. The two blade pieces go in the recess over it with the 0.05 mm feeler blade setting the gap, and the collimator's holder screws to the back. Tape the grating film into its carrier with the grooves along X. Slide the three carriers into their slots.
4. Fit the camera board on the end wall and the pose camera on the +Y face. Then the hall sensor. Solder the 3-wire cable into the breakout's S, G and + pads from the front, and pass a thread through the two tie holes below them so it runs across the back of the board. Bend the A3144's three leads 90° toward its back, away from the printed face, about 0.5 mm below the body. Push it into its pocket in the +X wall from inside, printed face toward the magnet, so the leads go out through the slot under the pocket and the body sits on the ledges either side of it. Feed the leads through the breakout's three holes from behind; seen from outside, VCC is on the right, at the square pad. Press the board flat on the wall and screw it on with an M2 × 5 through its M2 hole, then solder and trim the leads and tie the thread around the cable. A 0.8 mm recess behind the board's lower half leaves room for the thread and for solder that shows through the pads. The screw's tip comes 1.7 mm through the wall and passes about 1 mm from the mirror clamp as it turns, so don't use a longer one.
5. Screw the stepper to the lid with the four M2 × 4 from inside. The A3144 switches on one pole only, so pass each face of the magnet over the powered sensor first and glue it into the clamp's tab with the face that switches it facing out. Glue the mirror onto the pad between the notches, then put the clamp on the shaft.
6. Take the gripper off the wrist-roll horn and screw the puck on. Slide the housing onto the rail, then fit the lid so the mirror goes in through the open side. The two M3 × 35 bolts go in from the +X face and take a washer and nut each on the lid's motor pad, and the two M3 × 8 go through the lid ears.

## Controller tray

The [scan-mirror controller](../pcb/README.md#scan-mirror-controller) sits on its tray on the table behind the arm, 4 mm behind the Waveshare plate on the back of the base. The board's hall connector faces the arm and its USB edge faces away, toward the Jetson. Four posts with M3 heat-set inserts hold the board 6 mm up, which clears the leads underneath (3 mm at most), and the floor keeps them off a metal table. The walls stop below the board, so the jack, the screw terminal and the USB plug on its edges clear them. The strip behind the board has two slots for 1/4"-20 or M6 table screws. Each slot is a full hole pitch long, so on a 1 in or 25 mm grid there is a hole under both slots wherever the tray sits along them.

Press the four inserts into the posts, screw the board down with four M3 × 6, then screw the tray to the table. `tray_x` in the Params sheet moves it.

The arm reaches the tray only when it leans back over its base, which a scan of something in front of it never does. In the scanning pose it stays 62 mm away.

## Checks

`build_rig.py` runs these every build and writes the results to `build_report.json`.

- **Overlaps:** every pair of head parts, with up to 0.5 mm³ allowed. None found.
- **Mirror sweep:** the clamp, mirror and magnet turned a full circle in 10° steps. The closest approaches are the lid (0.5 mm), the housing (0.9 mm), the hall sensor (1.1 mm), the tip of the hall breakout's screw (1.3 mm; it is drawn at the thread's root, so about 1 mm to the thread), the filter cap (1.4 mm) and the objective (5.9 mm).
- **Wrist roll:** the head against the wrist bracket at every roll angle. The closest point is 1.4 mm, at 12.5 mm from the roll axis.
- **Wrist flex:** −95° to +95° at roll angles every 30°. No contact with the forearm anywhere.

## Arm load

Gravity torque on each joint, from the link masses in the SO-101 URDF, with the stock gripper swapped for the head at the head's centre of mass. The STS3215 stalls at 16.5 kg·cm (1.62 N·m) at 6 V, and the follower arm runs on 5 V, so treat the percentages as optimistic.

| Shoulder / elbow torque, N·m (% of stall) | Head | Scanning pose (render above) | Worst case: arm stretched out level |
|---|---|---|---|
| Stock gripper | | 0.13 / 0.38 | 0.86 (53%) / 0.45 (28%) |
| **Head as modelled (NEMA 8)** | **187 g** | **0.30 (18%) / 0.61 (37%)** | **1.21 (75%) / 0.70 (43%)** |
| NEMA 17 pancake instead (`RIG_MOTOR=17HM08`) | 280 g | 0.41 (25%) / 0.78 (48%) | 1.52 (94%) / 0.91 (56%) |
| No scan motor, the arm sweeps the line | 127 g | 0.22 (14%) / 0.49 (31%) | 1.01 (63%) / 0.57 (35%) |

The 12 V version of the STS3215 (30 kg·cm) would bring the worst case down to 41%, but it means swapping all six servos and the power supply. In practice: keep the arm folded the way the render shows while scanning, and don't park it stretched out level.

### The NEMA 17 option

The head was first drawn around a 150 g NEMA 17 pancake, which pushed the shoulder to 94% of stall, so the default is now the 60 g NEMA 8. The pancake is still a build option. The housing and every optic stay where they are; only the lid, the mirror clamp and the motor change.

| | 8HS11-0204S (default) | 17HM08-1204S |
|---|---|---|
| Motor | NEMA 8, 1.8°, 0.2 A, 60 g | NEMA 17 pancake, 0.9°, 1.2 A, 150 g |
| Head | 187 g | 280 g |
| Motor to lid | 4× M2 × 4 from inside; the long bolts end in washers and nuts on the lid | 2× M3 × 6 from inside; the long bolts thread into its lower holes |
| Microstepping for 0.29 mm lines at 150 mm | 1/32 | 1/16 |

The NEMA 8's 10 mm shaft reaches 5.5 mm into the clamp, with the pinch screw over it. Gravity on the mirror, clamp and magnet puts at most 0.014 N·cm on the shaft, about 1% of the motor's 1.6 N·cm holding torque. Build the pancake version with `RIG_MOTOR=17HM08 freecadcmd cad/build_rig.py`.

## Optics as built

The head holds the optics where [layout E](../optics/spectrograph_model.py) puts them. Layout E is the optics model of the parts that were bought:

- The field lens sits curved side toward the slit, and the collimator 26.76 mm behind the slit, where the slit's image through the field lens is.
- The stop is a 0.6 mm washer with a 4 mm hole on the objective's front face, with the long-pass disc in front of it.
- The grating sits right behind the collimator (6 mm), and the camera lens as close behind the grating as its barrel allows (16 mm).

`optics_check.py` traces the spacings the CAD builds with the Optiland model and prints them next to layout E ([`optics_as_built.txt`](optics_as_built.txt)):

- **Resolution:** 4.1 nm, as in layout E.
- **Spectrum and line:** the spectrum is 3.27 mm long, and the 43 mm line at 150 mm fits on the sensor.
- **Stop position:** the washer ends up 8.5 mm ahead of the objective's principal plane rather than 8.1 mm, because the lens barrel is an estimate. That costs a little light at the ends of the line: 52% gets through at 750 nm instead of 54%.
- **Light at the band ends:** at 500 and 1000 nm about 55% of the light reaches the sensor at the centre of the line, and a third at its ends. The wavelengths fan out over the 16 mm to the camera lens and partly miss its 6 mm aperture.
  - The model puts that aperture at the lens's principal plane. In a real M12 lens it usually sits a few millimetres behind the front glass, 4–8 mm from the grating, which would let 80–95% through at the centre.
  - Flat-fielding against the white reference removes whatever loss remains.

The 5 mm washer is worth printing to compare at first light. In the model it gets 14% more signal to the sensor at the centre of the line and 40% more at its ends, at the same 4.1 nm. But more light also gets through the slit and misses the sensor, and that stray light raises the floor under every spectral line. Compare the two on a neon frame.

## Rebuild or change it

You need FreeCAD 1.0 or newer (tested with 1.1.3). From the repo root:

```
python3 cad/vendor/so101/fetch_assets.py     # SO-101 meshes, once (17 MB, checked by SHA-256)
freecadcmd cad/build_rig.py                  # about 2 min: build, checks, STL/STEP, report, .FCStd
```

On Windows, `freecadcmd` is `FreeCADCmd.exe` in FreeCAD's `bin` folder. Running the script with the GUI instead (`freecad cad/build_rig.py`, from the repo root) builds the same thing and keeps the part colours in the saved file.

To change a number, open `so101_hsi_rig.FCStd`, edit the cell in the **Params** sheet and recompute. Everything that depends on it moves. Each value has a note saying what it is and where it came from. The joint angles (`q_*`) pose the arm. The STLs don't update on a recompute, so after a change either export the changed body by hand or make the same edit in [`rig/params.py`](rig/params.py) and rerun the script.

Renders (Blender 4.x and Pillow):

```
RIG_NO_EXPORT=1 RIG_RENDER_DIR=/tmp/rig_meshes freecadcmd cad/build_rig.py
blender -b -P cad/render/render_blender.py -- /tmp/rig_meshes /tmp/rig_renders
python3 cad/render/finish.py /tmp/rig_renders cad/renders
```

Optics check (needs `optiland`, like the model): `python3 cad/optics_check.py`

## Credits

The SO-101 URDF and meshes are from [TheRobotStudio/SO-ARM100](https://github.com/TheRobotStudio/SO-ARM100) (`Simulation/SO101`), used under the Apache License 2.0; a copy of the license is in [`docs/img/SO-ARM100_LICENSE.txt`](../docs/img/SO-ARM100_LICENSE.txt). The URDF is unmodified, and the .FCStd holds decimated copies of the meshes.

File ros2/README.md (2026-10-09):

# ROS 2: the SO-101 scan arm

ROS 2 Humble packages that move the SO-101 between viewpoints, sweep the scan mirror at each
one, record the spectrograph camera's view of every scan line, and log where the instrument was
for each, which is what the line-camera splat needs: its lines and their camera poses.

| Package | What's in it |
|---|---|
| [`so101_scan_interfaces`](so101_scan_interfaces) | Messages and services: `ScanLine`, `MirrorState`, `ScanLinePose`, `FrameStamp`, `ArmSafety`, `StartSweep`, `MoveMirror`, `StartRecording`, `CaptureReference` |
| [`so101_scan_hardware`](so101_scan_hardware) | ros2_control driver for the STS3215 servo bus (C++) with the arm's safety checks, plus `sts_scan`, `sts_calibrate` and a fake servo bus |
| [`so101_scan_safety`](so101_scan_safety) | `arm_estop` (a keyboard e-stop, and the reset), `check_plan` (a plan against the arm's soft limits), and the soft-limit model the sweep tools check with |
| [`so101_scan_description`](so101_scan_description) | URDF: the SO-101 with the scanner head on its wrist, the scan mirror as a joint, the line camera as the mirror sees it |
| [`so101_scan_bringup`](so101_scan_bringup) | `scan_arm.launch.py` and the controller and mirror settings |
| [`so101_scan_sweep`](so101_scan_sweep) | Mirror bridge, simulated mirror ESP32, `scan_sweep` (and its `--dry-run`), `make_plan` (views around a spot, or covering an object), `move_arm`, example plans |
| [`so101_scan_camera`](so101_scan_camera) | `line_camera` (the IMX219 through V4L2: frames to calibrated scan lines, and colour waterfalls of each sweep), `capture_reference`, `scan_to_dataset` (a scan to the splat trainer's dataset), a simulated camera and spectrograph |
| [`docker/`](docker), [`udev/`](udev) | The container for the Jetson Nano and stable device names |

## How it fits together

```mermaid
flowchart LR
    subgraph Jetson["Jetson Nano (Docker, ROS 2 Humble)"]
        sweep["scan_sweep<br/>runs a plan, logs line poses"]
        jtc["arm_controller<br/>(trajectory controller)"]
        drv["FeetechStsSystem<br/>ros2_control driver, 100 Hz"]
        bridge["scan_mirror_bridge"]
        rsp["robot_state_publisher<br/>URDF to TF"]
        cam["line_camera<br/>frames to scan lines"]
    end
    servos["SO-101<br/>5 x STS3215"]
    esp["Mirror ESP32<br/>TMC2209 + NEMA 8"]
    imx["IMX219 NoIR<br/>(spectrograph)"]
    sweep -- "FollowJointTrajectory" --> jtc --> drv -- "USB serial, 1 Mbaud" --> servos
    sweep -- "start_sweep / home" --> bridge -- "USB serial, 921600 baud, text" --> esp
    bridge -- "/scan_mirror/line" --> sweep
    imx -- "V4L2, raw RG10, 30 fps" --> cam
    cam -- "/line_camera/frame" --> bridge
    bridge -- "/scan_mirror/line" --> cam
    sweep -- "start / stop_recording" --> cam
    drv -- "/arm_safety/state" --> sweep
    drv -- "/arm_safety/state" --> bridge
    drv -- "/joint_states" --> sweep
    drv -- "/joint_states" --> rsp
    bridge -- "/joint_states (mirror)" --> rsp
```

For each viewpoint, `scan_sweep` moves the arm, waits for it to stop, and asks the bridge for a
sweep. The ESP32 steps the mirror line by line, holding still on each for about a camera frame,
and stamps each line with its own microsecond clock; the bridge maps that clock onto ROS time
(ping round trips, about 1 ms), so every line carries the ROS time the mirror settled.
`scan_sweep` then reads the arm's joints at that instant from `/joint_states`, adds the line's
mirror angle, and puts both through the URDF to get the head pose and the line-camera pose.

The spectrograph camera runs on its own 30 fps clock, so the bridge locks each sweep to it
([`frame_lock.py`](so101_scan_sweep/so101_scan_sweep/frame_lock.py)): from the `FrameStamp`
`line_camera` publishes for every frame (when the rows that see the slit were exposing), it fits
the frame clock, makes the line period a whole number of frames, and times every mirror move to
fall between two exposures, nudging the ESP32's line clock as the two drift apart. `line_camera`
keeps the frames whose whole exposure fell while the mirror held still on a line, bins each into
slit positions x wavelengths with the calibration kit's maps, and writes them into the scan's
folder while `scan_sweep` has it recording.

A few ROS 2 ideas this leans on:
- **ros2_control** splits a robot into a *hardware interface* (here, the C++ driver that reads
  and writes the servos) and *controllers* that run on top of it in a fixed-rate loop. The same
  controllers run on `mock_components/GenericSystem` when there's no arm.
- **The trajectory controller** takes a goal ("be at these joint angles in 3 s") as an *action*,
  interpolates it at 100 Hz, and reports when it's done.
- **TF** is ROS's tree of coordinate frames; `robot_state_publisher` keeps it current from the
  URDF and `/joint_states`, which is what RViz and Foxglove draw.

## Frames and conventions

All lengths in metres, angles in radians, quaternions x y z w.

| Frame | Where |
|---|---|
| `base_link` | SO-101 base; the table top is at z = -0.0024 |
| `scan_head_link` | Head frame from the CAD: origin on the wrist-roll horn face, +Z away from the wrist, +Y out of the scan window, X along the mirror shaft and the slit |
| `scan_mirror_link` | Turns with `scan_mirror_joint` |
| `spectrograph_optical_frame` | The objective as built, looking into the mirror |
| `line_camera_optical_frame` | The objective as seen in the mirror: a pinhole for one scan line. z is the view, x runs along the slit in pixel order. It turns twice as fast as the mirror (a mimic joint) |
| `scan_line_frame` | Middle of the in-focus scan line, 0.15 m along the view |
| `pose_camera_optical_frame` | The Pi NoIR pose camera |

The head's frames come from the CAD model until a head calibration exists: with `~/so101_scan/head_calibration.yaml` (from [`calibration/headcal`](../calibration/headcal/README.md)), `scan_arm.launch.py` builds the URDF with the measured mount, mirror, objective and pose camera instead.

**Mirror angle:** 0 is the 45° rest, where the head looks straight out of its window (+Y);
positive turns the view toward +Z. The hall sensor sits at -40°, which the firmware keeps as
`home_pos` (-711 microsteps); homing finds it and parks the mirror at 0. One microstep is
2π/6400 rad (0.05625°) of mirror and twice that of view.

**Arm joints:** zero is the URDF's zero pose (upper arm straight up, forearm level and
forward, wrist in line, scan window facing right). `sts_calibrate` records each servo's ticks
in that pose, which way it turns, and its range.

## Try it without hardware

On any 64-bit Linux machine with Docker (or the Nano itself):

```bash
ros2/docker/run.sh                 # builds the image the first time, then opens a shell
colcon build && source install/setup.bash
ros2 launch so101_scan_bringup scan_arm.launch.py use_mock_hardware:=true mirror:=fake camera:=fake foxglove:=true
```

In a second shell (`ros2/docker/run.sh` again):

```bash
ros2 run so101_scan_sweep scan_sweep --plan src/linescan-hyperspectral-splatting/ros2/so101_scan_sweep/plans/ring.yaml
```

The arm (mock) visits four viewpoints, the simulated mirror sweeps 107 lines at each, the
simulated camera records them, and a folder appears under `~/so101_scan/scans/` on the host.
`ros2 run so101_scan_camera scan_to_dataset /data/scans/<that folder> /data/datasets/ring` turns
it into a dataset `splat_train` reads. To watch, open
[Foxglove](https://foxglove.dev/download) on Windows, connect to `ws://<that machine's ip>:8765`, add a
3D panel, and turn on `/scan/markers`: every scan line lands on the table in front of the arm.
With ROS 2 on a desktop, `rviz:=true` does the same.

New viewpoints: `make_plan` finds arm poses that put the scan line on a spot from several
directions, and leaves out the ones the arm can't reach or that come too close to the table:

```bash
ros2 run so101_scan_sweep make_plan --target 0.26 0 0.03 --tilts 0 20 --azimuths 90 180 270 --out /data/plans/box.yaml
```

## Seeing a scan before and while it runs

**Plan around an object.** Give `make_plan` the object as a box (the middle of its bottom, then
its width, depth and height along `base_link` x, y and z, in metres) and it plans for coverage
([`coverage.py`](so101_scan_sweep/so101_scan_sweep/coverage.py)):

```bash
ros2 run so101_scan_sweep make_plan --object 0.26 0 --size 0.06 0.06 0.012 --out /data/plans/relief.yaml
```

It tries views from several tilts and azimuths aimed where they meet the box, works out which
points on its top and sides each view's sweep sees (inside the scan line's fan, within 30 mm of
focus, and facing the camera within 60°), and keeps the fewest views that see every point from
two directions, since a splat needs two to place a point in depth. It prints how much of each
face the plan covers; a face no reachable view sees (the side facing the arm's base, usually)
is named, so you can turn the object round for a second scan.

**Dry run.** `scan_sweep --plan <plan> --dry-run` plays a plan on the running stack without
moving anything ([`dry_run.py`](so101_scan_sweep/so101_scan_sweep/dry_run.py)): a see-through
copy of the arm moves through the viewpoints at the plan's speed in RViz or Foxglove
(`/scan/markers`), each sweep's scan lines appear where they would land, and a coverage plan's
box shows its surface turning from red to yellow to green as views see it. It checks every move
for the joint limits and for how close the arm and head come to the table (and the object) on
the way, the sweep against the bridge's mirror limits, and whether the controller, the mirror
(homed?) and the camera are up, then prints a report and exits 1 if anything would go wrong.
`--speed 4` plays it four times faster, and `--no-play` only checks. Try every new plan this way
before the real arm runs it.

**Colour waterfalls.** While a sweep runs, `line_camera` publishes it as images, a row per scan
line and the slit across: `/line_camera/scan_preview_true_color` (what your eye would see) and
`/line_camera/scan_preview_cir` (colour infrared: 800 to 900 nm as red, so plants glow red and
green paint doesn't), next to the grey `/line_camera/scan_preview`. They're worked out the way
`scan_to_dataset` makes the dataset, as reflectance against the latest white reference in the
46 bands from 500 to 950 nm, with the same colour maths as the splat renderer and the web viewer
([`waterfall.py`](so101_scan_camera/so101_scan_camera/waterfall.py)). Until a white is taken
the colours are relative to the calibration's lamp, close but not exact. Magenta marks a slit
bin with a saturated pixel: lower `exposure_us`. In Foxglove, add an Image panel on either topic.

## On the Jetson Nano

JetPack 4 is Ubuntu 18.04 and Humble needs 22.04, so ROS runs in the container
([`docker/Dockerfile`](docker/Dockerfile)); the Nano only needs Docker, which JetPack includes.
[`docker/run.sh`](docker/run.sh) explains each flag it passes.

1. **Clone the repo** on the Nano, let your user run Docker, and give the two USB devices
   stable names:
   ```bash
   sudo usermod -aG docker $USER      # then log out and back in, once
   sudo cp ros2/udev/99-so101-scan.rules /etc/udev/rules.d/
   sudo udevadm control --reload-rules && sudo udevadm trigger
   ls -l /dev/so101 /dev/scan_mirror
   ```
   If a name is missing, check the device's id with `lsusb` and fix its line in the rules file
   (the file says how).
2. **Build:** `ros2/docker/run.sh`, then `colcon build` inside (about 10 minutes the first time
   on a Nano; later builds only redo what changed). On JetPack 4.6, use
   [`jetson/ros.sh`](../jetson/README.md) in place of `run.sh`: its Docker can't build this image.

## First steps with the real arm

Each step checks one thing before the next one trusts it. Power the servos from their own
supply; keep a hand near the power switch for anything that moves, and once the motors are on,
`ros2 run so101_scan_safety arm_estop` open in another terminal (Enter stops the arm; see
[Arm safety](#arm-safety)). Stopping a launch leaves the motors holding the arm where it is;
`torque:=false` or that switch lets it go.

1. **Find the servos** (read-only, nothing moves):
   `ros2 run so101_scan_hardware sts_scan --port /dev/so101`
   should list ids 1 to 5 with their positions and voltages.
2. **Calibrate:** `ros2 run so101_scan_hardware sts_calibrate --port /dev/so101`.
   It switches the motors off (asking you to hold the arm first if they are holding it), then
   asks you to put the arm in the zero pose, move each joint through its range and nudge each
   joint the way it names, and writes `~/so101_scan/calibration.yaml`. The servos' homing
   offsets stay as they are unless you add `--write-homing-offset`, and a run you stop puts them
   back; the only other thing it writes is position mode, to a servo that isn't in it. Already
   calibrated the arm with LeRobot? `--from-lerobot <its json>` converts that file instead;
   check the wrist roll afterwards.
3. **Check the calibration with the motors off:**
   `ros2 launch so101_scan_bringup scan_arm.launch.py torque:=false mirror:=fake foxglove:=true`.
   The motors switch off as it starts, so hold the arm. Move it by hand: the model in Foxglove
   should follow joint for joint. A joint that turns the wrong way needs its sign fixed: stop
   the launch first (the driver and `sts_calibrate` can't share the servo port), then run
   `sts_calibrate --joints <name>`.
4. **First move, slowly:** launch again without `torque:=false`. The motors switch on holding
   the arm where it is; if a joint is well outside its calibrated range, the driver leaves them
   off and names the joint (stop the launch and recalibrate it, or move it into range with
   `torque:=false`). Then
   `ros2 run so101_scan_sweep move_arm --plan <plans>/one_view.yaml` moves at 20°/s to the
   view that looks straight down at the table.
5. **A scan with the simulated mirror:** first `ros2 run so101_scan_sweep scan_sweep --plan <plans>/one_view.yaml --dry-run`
   to see the move in Foxglove and read the report, then the same without `--dry-run`.
   The arm moves and holds while the fake mirror sweeps; check `arm_motion_max_rad` in the
   scan's `scan.json` to see how still the arm held.
6. **The real mirror:** flash and bench-test the ESP32 first
   ([`firmware/README.md`](../firmware/README.md): wiring, the driver's current, first run).
   Then launch with the default `mirror:=esp32` and run
   `ros2 service call /scan_mirror/home std_srvs/srv/Trigger`, which powers the motor and finds
   the hall sensor (needed again whenever the ESP32 restarts), and scan. If sweeps run
   backwards, stop the launch and send the ESP32 `CFG dir_inv=1` then `SAVE` (the firmware
   README shows how).

`<plans>` is `src/linescan-hyperspectral-splatting/ros2/so101_scan_sweep/plans`.

## Arm safety

The servo driver checks the arm every control cycle and stops it when something is wrong.
Stopping means holding: each servo's goal becomes where it is, and the driver ignores the
controller until a reset. If the cause is still there 5 s later, it switches the motors off.

| Check | Warns at | Stops at |
|---|---|---|
| Load, as a share of the servo's maximum torque | 60% | 90% for 1 s |
| Temperature | 55 °C | 65 °C for 1 s (an STS3215 cuts out at 70 °C on its own) |
| Supply voltage | 90% of what it read at start | 80% for 0.5 s |
| Stall: a joint 0.2 rad (11.5°) short of its goal and not moving | | after 0.5 s |
| The servo's own alarms (overload, overheat, voltage) | | two reads in a row |
| An e-stop | | at once |

**Soft limits** hold the arm back rather than stop it. Before a goal goes to the servos, the
driver puts it through the URDF: the head's collision box and the arm's links stay 10 mm above
the table, the head stays out of a cylinder around the `shoulder_pan` axis (80 mm radius, up to
140 mm) that holds the base and the electronics, and no joint holds more than 60% of its stall
torque against gravity (the CAD report has the stretched-out arm at 75%; the ring plan peaks
just under 50%). A step that would cross one isn't taken: the arm waits at the edge, any move
back is allowed, and `/arm_safety/state` says which limit held it.

**E-stop and reset:**

```bash
ros2 run so101_scan_safety arm_estop          # keep it open: Enter or space stops, l goes limp, r resets
ros2 run so101_scan_safety arm_estop --stop   # one action from a script; also --torque-off, --reset, --status
ros2 service call /arm_safety/estop std_srvs/srv/Trigger   # the same without arm_estop
```

Any other node can stop the arm by publishing `true` on `/estop` (`std_msgs/Bool`). The mirror
stops too (the bridge watches `/arm_safety/state` and `/estop`), and `scan_sweep` or
`move_arm` cancels its move, writes what it logged, and exits saying why. Reset with
`arm_estop --reset` rather than calling `/arm_safety/reset` yourself: it also restarts
`arm_controller`, so the controller starts from where the arm is instead of from the goal it
had when the arm stopped. A reset is refused while the cause is still there, a servo still too
hot for instance. With `torque:=false` the checks only report, as warnings.

**Check a plan before running it:** `ros2 run so101_scan_safety check_plan --plan <plans>/ring.yaml`
prints how far each viewpoint keeps the arm inside the workspace and how much each joint holds
against gravity, and checks the moves between viewpoints every 1°, with the head where the
launch puts it (headcal's calibration when there is one). It uses the same model and the same
numbers as the driver (all in the URDF's `<ros2_control>` block,
[`so101_scan.ros2_control.xacro`](so101_scan_description/urdf/so101_scan.ros2_control.xacro)), and
`scan_sweep` and `move_arm` run it from where the arm is before they move it.

All of this is software, so it needs the driver and the bus to be working; the servos' power
switch is the e-stop that always works. Mock hardware has no driver and so no `/arm_safety`,
but the plan check still runs.

## Scanning with the spectrograph camera

1. **Calibrate** the spectrograph with the kit in [`calibration/`](../calibration/README.md), in
   the sensor mode `line_camera` scans in: `python3 -m hsical plan ~/sessions/first_light
   --width 1640 --height 1232`. The 2x2 binned mode reads the slit's rows in about 20 ms, which
   leaves time for the mirror to move between frames at 30 fps; at full resolution a line would
   take two frames.
2. **Start the camera with the arm:** `ros2 launch so101_scan_bringup scan_arm.launch.py
   camera:=v4l2 camera_calibration:=/data/hsical/cal` (the folder `hsical calibrate` wrote).
   [`config/line_camera.yaml`](so101_scan_camera/config/line_camera.yaml) has its settings;
   `ros2 param set /line_camera exposure_us 8000` changes the exposure while it runs, and
   `~/preview` and `~/scan_preview` show the frames and the sweep so far, the sweep in colour
   too (see [the colour waterfalls](#seeing-a-scan-before-and-while-it-runs)).
3. **Take a white and a dark**, with the mirror still and the head over the PTFE sheet under the
   scan's lamp: `ros2 run so101_scan_camera capture_reference white`, then cap the lens and
   `capture_reference dark`. It says how bright the white is; aim for a peak of 50 to 90% of
   full scale and take the dark at the same exposure. The next scans use them, and so do the
   colour waterfalls.
4. **Scan:** `scan_sweep` has `line_camera` record into the scan's folder, and the bridge locks
   the sweeps to its frames (the log says how many frames a line takes). A plan's
   `camera: {record: required}` refuses to scan without the camera; `off` scans without it.
5. **Convert:** `ros2 run so101_scan_camera scan_to_dataset <scan folder> <dataset folder>`, or
   `python3 splat/tools/scan_to_dataset.py` on any computer with numpy, then `splat_train`.
   Values are reflectance against the white, 46 bands from 500 to 950 nm, 256 pixels along the
   slit, one head pose per sweep; `--help` lists the options.

Two things to check on the first real scan: that pixel 0 is the head's -X end of the slit (scan
something asymmetric; if the dataset comes out mirrored, set `slit_reversed: true`), and that
frames are stamped when the sensor starts reading out (`frames.csv` has every line `ok` and
sharp; if lines blur into their neighbours, `stamp_offset_us` shifts the driver's timestamps).

## What a scan writes

`<output_dir>/<name>_<date>-<time>/` (by default under `$SO101_SCAN_DATA/scans`, which is
`~/so101_scan` on the host):

- **`lines.csv`**, one row per scan line: `viewpoint, sweep_id, index, stamp_ns, hold_until_ns,
  settled, mirror_angle`, the head pose `head_x..head_qw` and the line-camera pose
  `cam_x..cam_qw` in `base_link`, and the five arm joints at the line's time. The mirror holds
  still from `stamp_ns` until `hold_until_ns`, so a camera frame belongs to a line when its
  whole exposure falls in between. `settled` is 0 when the mirror was still moving as the next
  line came due (a longer `line_period_s` fixes that).
- **`scan.json`**: the plan, and per viewpoint whether the move succeeded, lines expected and
  logged, line period and jitter, and how much the arm moved during the sweep.
- **`robot.urdf`** and **`plan.yaml`**: the URDF the poses came from (calibration included)
  and the plan as run, so the poses can be recomputed later.
- With the camera: **`frames/`** (`camera.json`, and `frames.csv` saying which frame each line
  got, when it was exposed, or why it got none), **`binned/`** (each sweep's lines as float32
  `[lines, slit bins, bands]` of mean raw counts, and the binning grid) and **`reference/`**
  (darks and whites). [`session.py`](so101_scan_camera/so101_scan_camera/session.py) describes
  them in full.

## The mirror ESP32's serial protocol

The firmware is in [`firmware/`](../firmware), and its protocol in
[`firmware/PROTOCOL.md`](../firmware/PROTOCOL.md): plain text at 921600 baud, so it can be tried
in any serial monitor. Each command, `VERB key=value ... id=<n>`, gets one `OK` or `ERR` reply
with the same id, and the ESP32 sends `EV` lines when something happens (a scan line, homing
done, a fault, a restart). The bridge uses `INFO`, `PING`, `STATUS`, `ENABLE`, `HOME`, `MOVE`,
`STOP` and stare-mode `SCAN`; its side of the protocol is
[`mirror_protocol.py`](so101_scan_sweep/so101_scan_sweep/mirror_protocol.py), and
`fake_scan_mirror` plays the ESP32 for the tests and for `mirror:=fake`. Locking sweeps to the
camera's frames uses `CFG` (the move and settle times), `NUDGE` (shift the line clock) and
`PERIOD` (change its rate).

## Development

```bash
colcon build && colcon test && colcon test-result --verbose
```

The tests need no hardware: the C++ driver runs against the fake servo bus, the bridge against
the simulated ESP32, one test brings up the whole stack and scans a two-viewpoint plan, another
plans views around a box and plays them with `--dry-run` (checking nothing moved), another
plays faults on the fake bus (an e-stop mid-scan, a blocked joint, a goal in the table), and the
camera tests run `line_camera` on a simulated camera that sees what the simulated mirror really
did, check its colour waterfalls against the scene's true colours, and replay a synthetic scan
through `scan_to_dataset` to check that the trainer's camera model sees the scene in every
pixel of every line.

The URDF has two generated parts. `so101_arm.xacro` comes from the vendored SO-101 URDF
(`scripts/so101_urdf_to_xacro.py`), and `scan_head_params.xacro` plus the head meshes come from
the FreeCAD model (`scripts/export_head_from_cad.py`, run with
`freecadcmd -c "exec(open('ros2/so101_scan_description/scripts/export_head_from_cad.py').read())"`
from the repo root after rebuilding `cad/`). The description tests fail when `so101_arm.xacro`
is stale or when the head's numbers disagree with `cad/build_report.json`.

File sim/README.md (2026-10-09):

# Instrument simulator

`hsisim` is a digital twin of the whole scanner: the SO-101 arm, the scan mirror, the objective and slit, the spectrograph and its IMX219 NoIR camera, and the pose camera beside them. Give it a scene with known spectra and a scan plan, and it renders the raw frames the camera would give at every scan line, then writes them out as a complete scan session in the rig's own on-disk format, together with the truth they were made from.

That makes every later stage testable before the parts arrive: the capture pipeline can convert a session as if it came off the Jetson, the [calibration kit](../calibration/) can calibrate the simulated instrument and turn its scans into reflectance, the [hand-eye calibration](../calibration/headcal/) can find a head that is off its CAD numbers, and the [splat trainer](../splat/) can be scored against a scene whose geometry, spectra and poses are all known.

<p align="center">
  Four panels. The relief target from above: a 5 by 5 block of coloured and patterned pillars inside a checker border, with the first sweep's scan lines drawn across it. A raw sensor frame of one line: a grey band of spectrum with dark absorption bars and horizontal stripes where the slit crosses pil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
  <br><sub>Left: the relief target from above, with every second line of the first sweep. Then one raw frame, of the red line, and the whole sweep as the slit really saw it next to what came out of <code>hsical calibrate</code> and <code>hsical apply</code>.</sub>
</p>

## Contents

- [Quick start](#quick-start)
- [What is simulated](#what-is-simulated)
- [The session on disk](#the-session-on-disk)
- [The end-to-end check](#the-end-to-end-check)
- [A hand-eye calibration scan](#a-hand-eye-calibration-scan)
- [Options](#options)
- [Limits](#limits)
- [Code map](#code-map)

## Quick start

On any PC with Python 3.10 or newer (no ROS needed), from this folder:

```bash
pip install -r requirements.txt
python -m hsisim selftest          # scan, calibrate, apply, compare with the truth: about 35 s
```

The self-test simulates two 12-line sweeps of the relief target plus a calibration session for the same simulated instrument, calibrates it with `hsical`, turns the sweeps into reflectance and checks the result against the truth. A whole scan, step by step:

```bash
python -m hsisim scan sim_out --plan ring                # 4 viewpoints x 107 lines: under 2 minutes at binning 4
cd ../calibration
python -m hsical calibrate ../sim/sim_out/calibration -o ../sim/sim_out/cal
python -m hsical apply ../sim/sim_out/cal ../sim/sim_out/frames/sweep_001 \
    --dark ../sim/sim_out/reference/dark --white ../sim/sim_out/reference/white -o ../sim/sim_out/spectra
cd ../sim
python -m hsisim evaluate sim_out sim_out/cal             # applies every sweep and compares with the truth
python -m hsisim preview sim_out                          # pictures in sim_out/preview/
python -m pytest                                          # 53 tests, about four minutes
```

## What is simulated

Everything that would make a real scan differ from the scene is in the frames, and the code for most of it is the repo's own, imported rather than copied, so the simulator can't drift from what it simulates.

| Stage | What is modelled | From |
|---|---|---|
| Scene | Solids on the table (a plane, boxes, spheres) with textured matte faces: solid, checker, bitmap and random-dot patterns. Lit evenly, as in a light tent, or by a halogen lamp with distance and angle fall-off and hard shadows. | `scene.py`, `scenes.py` |
| Spectra | The splat's materials, curve for curve, plus PTFE (the white reference) and a rare-earth tile with six narrow absorption bands at known wavelengths, shaped after didymium glass. | `spectra.py`, after `splat/src/spectra.cpp` |
| Objective and slit | The bought 15.6 mm f/3.9 objective, focused at 150 mm, images the 5 mm × 50 µm slit onto a 43.1 × 0.43 mm line. Every slit point is traced as a bundle of rays over the 4 mm aperture, so depth of field and occlusion at depth edges come out right. The slit is cut into three slices across its width, because light from each edge of the slit lands at a different place along the spectrum. | `linecam.py`, the Optiland design map |
| Spectrograph and camera | `hsical`'s synthetic instrument, deliberately off the design: spectrum shifted, rotated and stretched, barrel distortion, smile and keystone from the Optiland trace, slit taper and dust, camera lens blur, filter, grating and sensor response, the NoIR colour mosaic, pixel response and column pattern noise, hot pixels, black level 64, shot and read noise, 10-bit clipping. | `instrument.py`, `calibration/hsical/synth.py` |
| Arm and mirror | Head and line-camera poses from the URDF, through the ROS 2 package's own forward kinematics. The log differs from the truth as the rig's will: servo calibration offsets, whole encoder ticks with jitter, arm flex at each viewpoint, the mirror's homing offset and step error. With `--head-errors` the head itself is off its CAD numbers as a printed, hand-built one is (headcal's synthetic head: the head turned on the servo horn, the pose camera and the objective off their seats, the mirror's shaft tilted and its home wrong, the scan line a few percent long, some distortion along the slit), and lines.csv still logs the CAD head, as before a hand-eye calibration. | `arm.py`, `ros2/so101_scan_description`, `calibration/headcal` |
| Pose camera | The Pi NoIR camera v2 beside the spectrograph, as `headcal record` keeps its stills while the arm holds a viewpoint: grey, each 2 × 2 colour cell averaged, 1632 × 1232. Every pixel is 2 × 2 rays through a lens with real distortion (headcal's synthetic Pi camera lens) into the scene, so stills have its depth, occlusion and shadows; a pixel's grey is what the sensor's colour cells see of the material under the scan's light, with cos⁴ fall-off, a little lens blur, shot and read noise. | `posecam.py`, `calibration/headcal` |
| Timing | The rig's two clocks, run with its own code. The camera free-runs at 30 fps with the IMX219's rolling shutter: each row stops exposing 18.9 µs after the one before (in the 1640 × 1232 mode), so the slit's rows expose over a window 21 ms longer than the exposure. The bridge locks each sweep to those frames as `frame_lock.py` plans it, the mirror moves at the ESP32's start speed from each tick and settles for 3 ms, and `line_camera`'s matcher keeps the frames whose window falls inside the mirror's hold. The camera's stamps can be given an error; rows that then expose while the mirror moves see each angle along its path for as long as it was there. | `timing.py`, `ros2/so101_scan_sweep`, `ros2/so101_scan_camera` |

The default scene, **relief**, is a 60 × 60 mm plate with a 5 × 5 block of 8 mm pillars from 1 to 12 mm tall, their tops in different paints, papers, checkers, random dots, the rare-earth tile, PTFE and a word hidden in the near infrared. It is the textured relief the [splat README](../splat/README.md#training) suggests for pinning down sweep poses, which a flat board leaves loose, and it is simple to 3D print and paint. **board** is a flat target like the splat's synthetic scene, **white** is a PTFE sheet, and **tagboard** is the hand-eye calibration's ChArUco board (headcal's own definition, drawn as OpenCV draws it) laser-printed on Letter paper on card, lying near the target and turned a little, as a person would put it down.

## The session on disk

```
sim_out/
├── lines.csv          one row per scan line, written by ros2's own LinesCsv: viewpoint,
│                      sweep_id, index, stamps, mirror angle, head and line-camera poses
│                      in base_link, arm joints. What the rig would log.
├── scan.json          the run, in scan_sweep's format, plus "camera", "calibration_session"
│                      and "simulated" (every setting, the instrument's flaws, the objective)
├── robot.urdf         the URDF the poses came from, built from the ROS 2 package's xacro
├── plan.yaml          the scan plan as run
├── frames/
│   ├── frames.csv     one row per line, as the capture node logs it: sweep_id, index, status,
│   │                  file (the raw frame), seq (the camera's frame number), sof_ns (its row 0
│   │                  read out), exposure_start_ns and exposure_end_ns (its slit rows' window),
│   │                  exposure_us, gain, saturated_px, n_frames (frames that fitted the hold)
│   ├── camera.json    in line_camera's format: the sensor (size, bits, black level, Bayer
│   │                  order, fps, line_time_us and slit_rows), exposure, gain, slit_reversed,
│   │                  the stamps' stamp_offset_us, and under "simulated" the stamp error
│   └── sweep_001/     one hsical frame set per sweep: meta.json and frame_0000.npy ..., the
│                      raw 10-bit frame of each line (uint16)
├── reference/         dark/ and white/ (PTFE, reflectance 0.98): hsical frame sets at the
│                      scan's exposure and gain
├── calibration/       an hsical calibration session of the same simulated instrument:
│                      lamps, flat, wires, laser, darks
├── pose/              with --pose-camera: the pose camera's stills as `headcal record` keeps
│                      them: camera.json ("headcal pose frames v1"), frames.csv (index,
│                      stamp_ns, file, exposure_us, gain) and still_0000.npy ..., uint16 grey
│                      with black level 64, stamped on lines.csv's clock while a sweep runs
├── binned/            after `python -m hsisim bin`: the lines binned with a calibration, as
│                      line_camera writes them when it has one (binning.npz, sweep_001.npy ...)
└── truth/             what the frames were made from
    ├── lines_true.csv   lines.csv's columns with the true joints, mirror angles and poses
    ├── weights.npy      [line, h, material] each material's share of the light at each
    │                    slit position (times its shading)
    ├── materials.npy    [material, nm] their reflectance; nm.npy and h.npy are the axes
    ├── depth.npy        [line, h] distance (camera z) of what each slit position saw
    ├── pixel_maps.npz   the wavelength and slit position of every sensor pixel
    ├── frames_true.csv  when each kept frame really exposed (sof_ns and its slit rows' window),
    │                    its line's tick and the move onto it, and moving_share: the most of any
    │                    slit row's exposure spent while the mirror was off the line
    ├── head.json        with the pose camera or --head-errors: the head as it really is and as
    │                    the CAD has it (headcal's HeadGeometry), the pose camera's lens, the
    │                    tag board's pose; head_calibration.yaml is the true head as headcal
    │                    writes a calibration
    ├── pose_camera.json, stills_true.csv
    │                    the pose camera's true lens and pose in the head, and where it really
    │                    was for each still
    └── scene.json, truth.json
```

Conventions, the same as the rig's:

- Sweeps are numbered from 1, as the mirror bridge numbers them, and frames by the line's index in its sweep.
- The slit position h runs from −1 to +1 along the line camera's +x axis, and on the sensor the slit row grows with h. So the first rectified slit row is the camera's −x end, which is pixel 0 of the splat's dataset. With `--slit-reversed` the camera is mounted the other way: the frames (and the calibration session's) come out mirrored along the slit, `hsical calibrate` keeps the rows as they are, and camera.json's `slit_reversed: true` tells `scan_to_dataset` to flip them, so the dataset comes out the same.
- Frames are as the camera gives them, so `hsical apply` works on a sweep folder unchanged.
- Times are as the rig logs them. In lines.csv a line's stamp is when the mirror settled (line 0 of a sweep is already there at its tick) and its hold ends 50 µs before the next tick. In frames.csv a frame's stamp is its row 0's read-out plus `stamp_offset_us`, and its window runs from the first slit row's exposure start to the last one's read-out, as `SensorTiming` works it out. The line period is a whole number of frames, enough for one window plus the mirror's move and margins: at a 20 ms exposure, two frames (66.7 ms) a line where the plan asks for one.

`hsisim.truth.ScanTruth` reads the truth back: `ScanTruth("sim_out").reflectance(line, nm)` is what each slit position of a line really saw.

Sessions come out raw, as from a rig scanning without a calibration, because the simulated instrument is calibrated afterwards. `python -m hsisim bin SESSION CAL` then bins the lines with `so101_scan_camera`'s own `LineBinner`, as `line_camera` would have with that calibration, into binned/, and fills in camera.json's calibration and binning. `scan_to_dataset` doesn't need it (it bins raw frames itself, given `--calibration`); `headcal solve` does.

## The end-to-end check

`python -m hsisim evaluate` (and the self-test) turns every sweep into reflectance with `hsical` and compares it with the truth three ways:

- **Reflectance:** every rectified cell that saw a single material, a few blur widths away from any edge, against that material's reflectance at the slit position and wavelength the cell really sees.
- **Wavelength:** the rare-earth tile's six absorption bands, fitted in the scan's own spectra, against the same fit to the true spectrum blurred to the calibrated resolution. No lamp is in the scene, so this checks the calibration's wavelengths on scene light.
- **Geometry:** where each rectified slit row really looks against where its row number puts it, and each line's profile along the slit against the truth's, which also proves the slit runs the right way.

Results at binning 4 (seed 7, uniform light), the self-test and the full `ring` plan:

| Check | Limit | Self-test, 24 lines | Ring, 428 lines |
|---|---|---|---|
| Median reflectance error, as a ratio | 1% | 0.00% | 0.00% |
| RMS reflectance error, as a ratio (one frame per line) | 5% | 1.6% | 1.6% |
| RMS reflectance error | 0.02 | 0.009 | 0.009 |
| Worst rare-earth band centre | 0.30 nm | 0.07 nm | 0.04 nm |
| Worst slit row position | 0.30 px | 0.16 px | 0.16 px |
| Median shift of a line's profile along the slit | 0.5 px | 0.15 px | 0.15 px |
| Correlation with the true profile (mirrored) | 0.9 | 0.997 (0.09) | 0.997 (0.06) |

The slit rows' error is the calibration's: the keystone fit puts rows up to 0.16 px (binned) from where they really look, in a smooth S along the slit, and the profile shifts follow it.

## A hand-eye calibration scan

The [hand-eye calibration](../calibration/headcal/) finds where the scanner head really sits on the wrist, and where the pose camera, the objective and the mirror sit in it, from a scan of its tag board and the pose camera's stills. The simulator renders that scan for a head that is off its CAD numbers, as the rig would take it, so a calibration can be checked against the true head:

```bash
python -m hsisim scan he --plan headcal --scene tagboard --pose-camera --head-errors 1   # 22 viewpoints, slow
cd ../calibration
python -m hsical calibrate ../sim/he/calibration -o ../sim/he/cal
cd ../sim
python -m hsisim bin he he/cal                     # the binned lines line_camera would have written
cd ../calibration
python -m headcal solve ../sim/he ../sim/he/pose -o ../sim/he/headcal
```

`python -m hsisim handeye` does all of that on every other viewpoint of the plan, with sweeps of 54 lines four steps apart, and compares the head headcal finds with the true one (truth/head.json) in headcal's own terms: about five minutes. Seed 7:

| Against the true head | Perfect arm (`--errors 0`) | The simulator's arm |
|---|---|---|
| Line camera's rays on the board, median: headcal (CAD head) | 0.03 mm (4.5 mm) | 1.9 mm (4.5 mm) |
| Pose camera on the wrist: headcal (CAD head) | 0.01 mm, 0.005° (2.3 mm, 3.2°) | 1.4 mm, 0.4° (2.3 mm, 3.2°) |
| Pose camera lens: focal length, centre | 0.12 px, 0.10 px | 0.24 px, 0.10 px |
| Scan line posed from the logged arm, median: headcal (CAD head; true head) | 0.02 mm (4.5 mm; 0) | 1.0 mm (3.3 mm; 1.6 mm) |

With a perfect arm headcal finds the head as well as on its own synthetic scans. With the simulator's arm (servo offsets of 0.25°, whole encoder ticks, and 0.5 mm and 0.2° of flex at each viewpoint) it can't tell the servos' constant offsets from the head's place on the wrist, so it puts them into the mount: the head it finds is further from the true one, but the scan line posed from what the rig logs lands nearer where it really was (1.0 mm) than it would through the true head (1.6 mm). What is left is the flex, different at every viewpoint, which the splat trainer's pose correction per sweep is there for. The last row is the error `scan_to_dataset --urdf` hands the trainer.

## Options

```bash
python -m hsisim scan --help
```

- `--plan ring`, any plan file from `make_plan`, or `headcal` (the hand-eye calibration's plan, calibration/headcal/plans); `--views down,tilt25_az90` keeps only some viewpoints, and `--lines`, `--steps-per-line`, `--start-angle-deg` and `--line-period-s` override the sweep.
- `--scene relief|board|white|tagboard` and `--lighting uniform|lamp`.
- `--binning 4` (the default), 2, or 1 for the full 3280 × 2464 sensor. At binning 4 a line takes about 0.17 s and 1 MB on disk. At binning 1 it takes about 6 s and 16 MB, with 1.4 GB of memory, so a full ring plan is most of an hour and 7 GB.
- `--seed`: the instrument's flaws, the pose errors and the noise all follow it; the same seed gives the same lines.csv and frames.
- `--errors 0` for perfect poses (the log is then the truth), or 2 for twice the default errors.
- `--exposure-ms`, `--gain`, `--slices` and `--rays` (rays per slit point).
- `--fps` (30 by default, 21 at binning 1, as the IMX219's modes allow); an exposure must fit in one frame.
- `--stamp-error-us 15000` makes the camera's stamps 15 ms late, as a driver whose timestamp isn't row 0's read-out would. The bridge locks to the stamps, so the frames really expose earlier, and once the error is more than the lock's slack can take (9.3 ms late in the self-test's sweeps of 16 steps a line, 13.6 ms in the ring plan's 2-step lines) the first slit rows catch the end of the mirror's move. `--stamp-offset-us -15000` is `line_camera`'s correction and gives back the exact session. truth/frames_true.csv says how much of each line moved.
- `--slit-reversed`: the camera mounted the other way along the slit.
- `--pose-camera` also renders the pose camera's stills into pose/, `--pose-stills` a sweep (1 by default; the arm holds still through a sweep, so more only adds noise samples), at `--pose-exposure-ms` (20, with the exposure level set as `record --auto 0.7` would). A still takes about 5 s. Needs OpenCV.
- `--head-errors 1` puts the head off its CAD numbers by as much as a hand-built one is likely to be (2 for twice that). The frames and stills come from the true head, lines.csv from the CAD one, and truth/head_calibration.yaml has the true head. Needs OpenCV.

`python -m hsisim bin SESSION CAL [--slit-bins 256]` bins a session's lines with a calibration, as `line_camera` does when it has one.

In Python, `hsisim.session.simulate(out, plan, Settings(...))` takes the same settings, and `Settings.truth` overrides any of hsical's instrument flaws, for example `{"blur_px": 12.0}` for a soft camera lens.

## Limits

- **Matte surfaces only**: no specular highlights, no light bouncing between surfaces, no fluorescence.
- **Ideal objective and mirror**: a thin lens with a Gaussian blur, a flat mirror that reflects every wavelength equally. Stray light and ghosts aren't modelled.
- **Only the mirror moves, and cleanly**: the arm holds still through a sweep, the mirror moves at a steady speed and is still the moment it gets there (the 3 ms settle is margin, not ringing), and the camera's and the ESP32's clocks run at the same rate and agree but for the stamps' error.
- **The pose camera takes stills, not video**: a still is rendered when the recorder would keep one, with the arm holding a viewpoint, so there are none from while the arm moves and no motion blur or rolling shutter in them. The lens is a pinhole with OpenCV's distortion, focused everywhere but for a slight blur.
- **No drift**: the instrument stays as calibrated, with no temperature changes between the calibration session and the scan.

## Code map

```
hsisim/
├── __main__.py     command line: scan, selftest, evaluate, bin, preview
├── repo.py         imports calibration/hsical, headcal and the ROS 2 packages' modules; builds robot.urdf
├── spectra.py      the spectral library and preview colours
├── scene.py        solids, textures, lighting, ray casting
├── scenes.py       relief, board, white, tagboard
├── linecam.py      the objective and the rays one scan line traces
├── instrument.py   hsical's synthetic spectrograph, rendering scene light into raw frames
├── arm.py          true and logged poses
├── session.py      a whole scan session on disk
├── timing.py       the camera's and the mirror's clocks: the frame lock, rolling shutter, stamps
├── posecam.py      the pose camera and its stills
├── binned.py       binned/, as line_camera writes it with a calibration
├── handeye.py      headcal's calibration scan, solved and compared with the true head
├── truth.py        reading the truth back
├── evaluate.py     the end-to-end check
└── preview.py      pictures of a session
tests/              53 tests: rays, scenes, rendering, the session format, timing, the pose camera, end to end
tools/              readme_figure.py draws img/simulator.png
```

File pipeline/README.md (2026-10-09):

# pipeline: virtual first light

Every stage of the rig's software is built and tested on its own. The simulator renders raw
frames, the calibration kit calibrates the spectrograph, the capture side's converter turns a scan
into a dataset, the trainer fits a splat, the exporter packs it and the web viewer opens it. This
folder runs them in a row, the way a real scan will go through them. Each hand-off is checked
against the simulator's truth. Once the parts arrive, first light is the same command with a
different config.

```bash
python3 pipeline/first_light.py                                   # the simulator's ring scan: about 10 minutes on 4 cores
python3 pipeline/first_light.py pipeline/configs/sim-quick.yaml   # a smaller one: about 2 minutes
python3 pipeline/first_light.py pipeline/configs/rig.yaml --set scan.path=~/so101_scan/scans/<scan>
```

It needs Python 3.10 or newer with the simulator's packages (`pip install -r sim/requirements.txt`:
numpy, scipy, PyYAML and xacro), CMake with a C++17 compiler, and Node 18 or newer for the viewer
check, which is skipped without Node. If `build/splat` doesn't have `splat_train` and
`splat_export` yet, the first stage builds them, with CUDA when CMake finds it.

## Contents

- [The chain](#the-chain)
- [The checks](#the-checks)
- [First light with the real parts](#first-light-with-the-real-parts)
- [Relief or flat board: how well the poses come back](#relief-or-flat-board-how-well-the-poses-come-back)
- [Options](#options)
- [Files](#files)

## The chain

| Stage | What runs | What it writes in `build/first_light/<name>/` |
|---|---|---|
| build | CMake, only if the tools are missing | `build/splat/splat_train`, `splat_export` |
| scan | `python -m hsisim scan` from [`sim/`](../sim/README.md) | `scan/`: a scan session in the rig's format, plus `truth/` |
| calibrate | `python -m hsical calibrate` from [`calibration/`](../calibration/README.md) on the session's calibration captures | `cal/` |
| convert | [`splat/tools/scan_to_dataset.py`](../splat/tools/scan_to_dataset.py), the capture side's converter | `dataset/`: the trainer's format |
| truth | [`sim_truth.py`](sim_truth.py) (simulated scans only) | `dataset/gt/`: true poses, mirror angles and noise-free lines |
| train | `splat_train` | `train/`: the splat, the refined poses, `log.csv`, previews |
| export | `splat_export --reference` | `splat.lsplat` for the [viewer](../viewer/README.md), and the C++ renderer's spectra at a grid of pixels |
| viewer | [`viewer_check.mjs`](viewer_check.mjs) | `viewer_check.json` |

Then `report.md` and `report.json` list every number the stages measured, with the config's limit
where it sets one. The command exits with 0 only if every check passes, so CI can run it as is.
`logs/` keeps each stage's output.

`truth` writes the same `gt/` folder that `splat_synth` writes for its own synthetic datasets, so
`splat_train` and `splat_render residual` score a simulated scan without any changes. Lines are
matched to the simulator's by sweep and mirror angle, so it still works if the converter leaves
some out.

The viewer check loads the exported file with the viewer's own `format.js` and `probe.js` in Node,
with no browser. It compares their spectra with the C++ renderer's at the reference pixels
`splat_export --reference` wrote. The viewer's own tests ([`viewer/test`](../viewer/test/run.mjs))
already check the WebGL2 image against the same kind of reference in headless Chromium, so this
check doesn't do that again.

## The checks

Results from the nightly config, [`configs/sim.yaml`](configs/sim.yaml): the relief target on the
ring plan, four viewpoints of 107 lines each, seed 7, 256 pixels by 46 bands, 3000 steps on a
4-core CPU.

| Check | What a failure would mean | Limit | Result |
|---|---|---|---|
| hsical's own calibration checks | the simulated instrument no longer calibrates | pass | pass |
| Lines left out, values filled in | frames lost between the session and the dataset | 0, ≤ 0.1% | 0, 0 |
| Reflectance against the truth: \|median ratio − 1\|, rms | the white reference, darks or band sums are off | ≤ 1%, ≤ 3% | 0.00%, 1.0% |
| Slit profile correlation with the truth, and with the truth mirrored | pixel 0 is at the wrong end of the slit | ≥ 0.99, ≤ 0.5 | 0.999, 0.02 |
| Slit profile shift | the slit bins are off by part of a pixel | ≤ 0.25 px | 0.06 px |
| RMSE against the measured lines, and against the truth's noise-free lines | the splat doesn't fit the lines | ≤ 0.025, ≤ 0.03 | 0.014, 0.019 |
| Pose error after training, and after over before | pose refinement stopped working | ≤ 2.5 px, ≤ 0.7 | 1.70 px, 0.47 |
| The exported file, decoded as the viewer decodes it, against the scene | the export's quantisation went wrong | ≤ 0.005 rms | 0.0002 |
| The viewer's probe against the C++ renderer | the viewer and the trainer disagree on the format or the model | ≤ 5 × 10⁻⁴ | 6 × 10⁻⁵ |
| How much of the default view's middle the splat covers | the viewer opens looking at nothing | ≥ 50% | 81% |

The logged head poses start 2.0 mm and 1.0° from the truth (the simulator's default arm and
mirror errors), which is 3.60 px rms on the line cameras. Training brings that down to 1.70 px,
about 0.28 mm on the table. The quick config ([`configs/sim-quick.yaml`](configs/sim-quick.yaml),
two viewpoints, 128 pixels by 23 bands, 600 steps) runs every stage in about 100 seconds. It keeps
the same limits on the conversion and only asks that training doesn't make the poses worse.

## First light with the real parts

[`configs/rig.yaml`](configs/rig.yaml) runs the same stages on a scan folder from the rig: what
`scan_sweep` and `line_camera` write, as [ros2/README.md](../ros2/README.md#scanning-with-the-spectrograph-camera)
describes.

```bash
python3 pipeline/first_light.py pipeline/configs/rig.yaml --set scan.path=~/so101_scan/scans/ring_20261010-140000
```

If `line_camera` ran with a calibration, its lines are already binned and that's all it needs.
Otherwise `--set scan.calibration=<hsical calibration>` bins the raw frames, or
`--set scan.calibration_session=<hsical session>` calibrates one first. There is no truth for a
real scan, so the checks are the ones a real scan allows: how many lines made it into the
dataset, how many values had to be filled in, how well the splat fits the measured lines, and
whether the viewer reads the file. The two first-light questions in ros2/README.md, which end of
the slit is pixel 0 and whether frames are stamped right, show up in `train/preview/`, where the
measured lines sit beside the trained ones for each sweep. Then open `splat.lsplat` in the viewer.

The simulator's slit-profile check is how this chain proves the converter puts pixel 0 at the head's
−X end. On the rig, scan something asymmetric first.

## Relief or flat board: how well the poses come back

The trainer refines one head pose per sweep. On `splat_synth`'s flat board, refining only the poses
against the true scene, from noise-free lines, stops at about 0.3 px at 128 px (see
[splat/README.md](../splat/README.md#training)). Turning a sweep slightly about the board while
shifting it to keep the board in place barely changes what a narrow fan of lines sees of a flat
surface, so the loss is nearly flat in that direction. The splat README suggested a target with
textured relief to pin that down, and the simulator's default scene is one: a 60 mm plate with
5 × 5 pillars 1 to 12 mm tall, their tops painted, patterned and dotted. Its `board` scene is a
flat target like the splat's.

[`pose_floor.py`](pose_floor.py) runs both scenes through the chain up to training, then trains
each twice more:

- **Joint:** the scene and the poses together, from the logged poses. This is what the chain does
  and what the rig will do.
- **Scene at the true poses:** the scene alone, on a copy of the dataset with the truth's poses
  and mirror angles (`--no-poses`). This is the best scene the lines can give.
- **Poses only:** from the logged poses, against that scene held fixed (`splat_train --init-scene
  --freeze-scene`). This was meant to show the floor the geometry leaves, with no error in the
  scene to blame.

From the CI run on the pull request that added this, at 256 px, 46 bands and 3000 iterations. A pixel
is 0.16 mm on the table at the 150 mm working distance.

| Plan | Scene | Logged poses | Joint training | Scene at the true poses (RMSE vs truth) | Poses only, scene frozen |
|---|---|---|---|---|---|
| ring, 4 sweeps | relief | 3.60 px (0.59 mm) | 1.70 px (0.28 mm) | 0.0193 | 8.43 px (1.38 mm) |
| ring, 4 sweeps | board | 3.60 px (0.59 mm) | 0.49 px (0.08 mm) | 0.0092 | 0.38 px (0.06 mm) |
| ring16, 16 sweeps | relief | 6.29 px (1.03 mm) | 1.76 px (0.29 mm) | 0.0366 | 7.57 px (1.24 mm) |
| ring16, 16 sweeps | board | 6.29 px (1.03 mm) | 0.45 px (0.07 mm) | 0.0101 | 0.39 px (0.06 mm) |

What this says:

- **The relief doesn't pin the poses down better, yet.** Trained the way the chain trains, the
  board's poses come back to under half a pixel and the relief's to about 1.7, from either plan;
  both are well under a millimetre. The relief's scene is harder to learn: even at the true poses
  its lines are fitted twice as badly as the board's (worse from sixteen views, whose 25° views
  see the pillars' sides, in the same 3000 iterations), and the poses bend to absorb what the
  scene gets wrong.
- **Against a fixed relief scene, the poses run away.** On the board the frozen run lands at 0.4 px.
  On the relief it ends 7.6 to 8.4 px off, fitting the lines ten times worse than the true poses do.
  Started at the true poses it stays there (0.001 px after 600 steps), and in a one-off test on the
  ring plan with the pose steps cut to a tenth and to a fiftieth it still drifted away, more slowly
  (to 6.5 and 4.1 px). So it's the shape of the loss, not the step size: the pillars' edges and fine
  patterns make a sharp minimum at the truth, and the logged poses, 3.6 px off, are already outside
  it, where the nearest way downhill leads elsewhere. Joint training gets in because its scene
  starts as a blurry plane and sharpens as the poses settle.
- **For the rig:** keep joint training. A sharp scene would only help once the poses are within a
  pixel or so of the truth, which better hand-eye calibration, or a coarse-to-fine pose stage
  (poses against a blurred scene first), might give. Neither is tried here.

```bash
python3 pipeline/pose_floor.py                                      # the ring plan
python3 pipeline/pose_floor.py --plan pipeline/plans/ring16.yaml    # sixteen viewpoints
```

[`plans/ring16.yaml`](plans/ring16.yaml) is a plan the arm can reach. It looks at the same spot as
`ring.yaml`: straight down, eight views 15° off vertical every 45° of azimuth, and seven views 25°
off. The arm can't lean 25° away from its base. `make_plan` wrote it, and the rig can run it as it
is.

## Options

```bash
python3 pipeline/first_light.py --help
```

- `CONFIG`, a YAML file: [`sim.yaml`](configs/sim.yaml) (the default), [`sim-quick.yaml`](configs/sim-quick.yaml)
  or [`rig.yaml`](configs/rig.yaml). Any key it leaves out takes the value in `DEFAULTS` at the
  top of `first_light.py`.
- `--set KEY=VALUE` overrides a value, read as JSON where it parses. Examples:
  `--set sim.scene=board`, `--set sim.views='["down"]'`, `--set train.iterations=500`,
  `--set train.cpu=true`, or `--set limits.pose_error_px_max=null` to drop a check.
- `--out DIR`. The default is `build/first_light/<name>`, which git ignores.
- `--from STAGE` and `--to STAGE` rerun part of the chain and reuse what the earlier stages left.
  For example, `--from train --set train.iterations=6000` retrains without scanning again.
- `train.args` and `convert.args` pass extra flags straight to `splat_train` and
  `scan_to_dataset.py`.

## Files

```
first_light.py      the command: config, stages, checks, report
sim_truth.py        the simulator's truth as the dataset's gt/, and the conversion's checks
viewer_check.mjs    the viewer's reader and probe on an exported splat, against the C++ renderer
pose_floor.py       relief against flat board, three ways of training
configs/            sim.yaml (nightly), sim-quick.yaml (pull requests), rig.yaml (first light)
plans/ring16.yaml   sixteen viewpoints of the ring's spot
tests/              unit tests: python -m pytest pipeline/tests
```

[`.github/workflows/first-light.yml`](../.github/workflows/first-light.yml) runs `sim.yaml` every
night and on demand, and `sim-quick.yaml` on pull requests that change this folder, the simulator,
the converter, the splat tools or the viewer's scripts. Each run keeps `report.md`, the logs, the
sweep previews and the splat as an artifact.

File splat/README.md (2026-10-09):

# splat: line-camera Gaussian splatting

This is the reconstruction side of the rig. The spectrograph never takes a
picture: each camera frame is one line of the scene (every pixel along the
slit, every wavelength), the scan mirror sweeps that line across the object,
and the arm moves the head between sweeps. So the training data is thousands of
one-row images, each with its own pose, and the splat has to be rendered
through a camera that has a single row of pixels.

What's here:

- a **line-camera renderer** for hyperspectral Gaussians: a CPU reference (in
  `float` or `double`) and a CUDA rasterizer that matches it, written for the
  Jetson Nano's CUDA 10.2
- a **synthetic pushbroom dataset**: a known scene with realistic spectra, scanned
  through the head's mirror geometry from `cad/`, with the kind of pose errors
  the arm will have, plus the ground truth to score against
- a **trainer** that fits the Gaussians to the lines and corrects each sweep's
  head pose at the same time, with the backward pass on the CPU or the GPU
  ([Training](#training))
- **material maps** for a trained splat: each Gaussian's material by spectral
  angle against a library, clusters found without one, and each material's
  share by linear unmixing, for the web viewer to show
  ([Material maps](#material-maps))
- tools to make and inspect datasets and to train, and unit tests that pin the
  math down

<table>
  <tr>
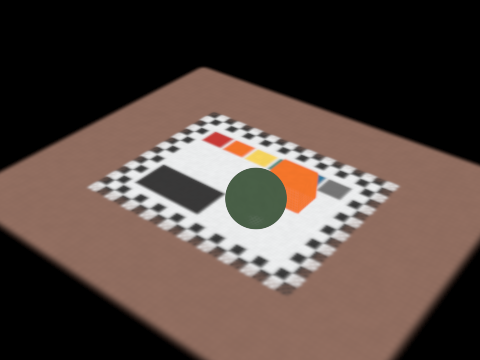
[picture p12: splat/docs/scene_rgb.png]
The synthetic scene in true color: a white board with a checker border, six paint patches, a black panel, a green ball and an orange box, on a wooden table.
    <td width="50%"></td>
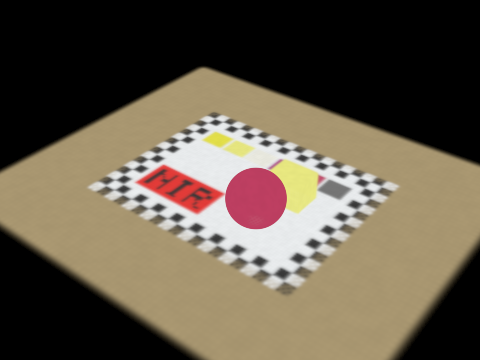
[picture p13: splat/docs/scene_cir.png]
The same scene in color infrared: the black panel shows the word NIR, the green ball turns red and the orange box turns yellow.
    <td width="50%"></td>
  </tr>
</table>

The synthetic scene, rendered by this code from its overview camera (an image
is just a stack of line cameras, one per row). Left: true color, computed from
each pixel's 500–950 nm spectrum. Right: color infrared, with 800–900 nm shown
as red, red as green and green as blue. The black panel hides the word "NIR",
printed in carbon black on a dye that is black to the eye but clear past
740 nm, and the green ball turns red because leaves reflect strongly in the
near infrared.

## What the scanner records

<table>
  <tr>
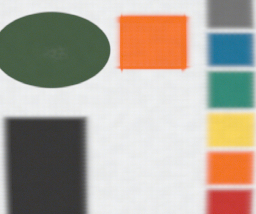
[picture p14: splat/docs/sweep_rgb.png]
One sweep looking nearly straight down, in true color: the ball, the box, the paint patches and the black panel.
    <td width="50%"></td>
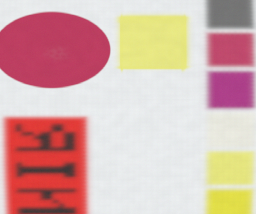
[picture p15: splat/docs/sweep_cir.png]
The same sweep in color infrared, with the word NIR readable on the panel.
    <td width="50%"></td>
  </tr>
</table>

One sweep looking nearly straight down: 214 scan lines of 256 pixels, stacked in the
order the mirror took them. The lines are 0.29 mm apart on the board and the
pixels 0.16 mm, so round things look squashed; the renderer knows each line's
pose, so this never has to be resampled into a square-pixel image.

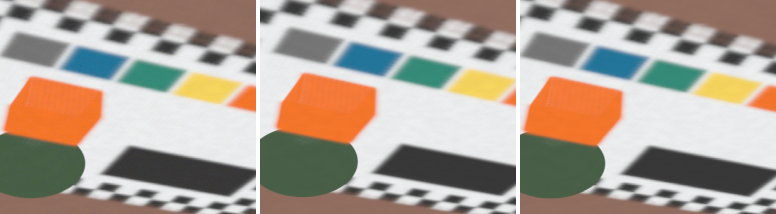
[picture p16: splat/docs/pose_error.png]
Three panels of one oblique sweep: the measured lines, the scene rendered at the recorded poses, which is shifted and rotated, and the scene rendered at the true poses, which matches.


Why poses need refining: one oblique sweep as measured (left), the true scene
rendered at the pose the arm reported (middle), and at the true pose (right).
A head pose that is off by 3.3 mm and a quarter of a degree moves the whole
sweep.

| Lines rendered from the true scene at... | RMSE vs measured |
|---|---|
| the recorded poses | 0.186 |
| the true poses | 0.016 (the noise level) |
| the true poses, vs the noise-free lines | 0.006 |

(Reflectance units, `splat_render residual` on the default dataset. The last
row is what is left from modelling the slit as a Gaussian rather than a box.)

## The model

### A line camera

Each scan line is a pinhole camera with one row of pixels. In camera
coordinates (x along the slit, y across it, z forward, in metres):

```
u = f x / z + cu        along the slit, in pixels; pixel p covers [p, p + 1)
v = f y / z             across the slit; the slit sits at v = v_slit
```

`f` is the objective-to-slit distance measured in pixels, where a pixel is the
slit's length over the pixel count: 17.91 mm over a 5 mm slit binned to 256
pixels gives f = 917 px, so a line covers 41.9 mm at 150 mm, as in the
Optiland model. Each line also carries a
blur: `sigma_u` along the slit (pixel pitch plus optics) and `sigma_v` across it
(the 50 µm slit's width plus optics). See
[`line_camera.hpp`](include/linesplat/line_camera.hpp).

### The mirror and the virtual camera

The objective looks down the head's -Z axis into the 45° scan mirror, and the
scene sees a mirror image of the camera, the *virtual camera*. Turning the
mirror by an angle turns the virtual camera's view by twice that angle. A
reflection flips handedness, so the virtual camera's y axis is negated to keep
it a proper rotation, and `v_slit` flips sign with it.

The pose of line *l* in sweep *s* is

```
camera_in_world(l) = head_in_world(s) * virtual_camera_in_head(mirror_angle(l))
```

`head_in_world` comes from the arm (or the AprilTag board) and is fixed for the
whole sweep; the mirror angle comes from the stepper's step count. The head
geometry is `cad_head_model()` in
[`scan_model.cpp`](src/scan_model.cpp), taken from the head layout in
`cad/rig/params.py` with the Edmund 20 × 20 × 3 mm mirror. Mirror angles follow
the ROS 2 `ScanLine` message: radians, 0 at the 45° rest, right-handed about the
head's +X (shaft) axis.

Splitting the pose this way is what makes training possible. A single line says
almost nothing about where it sat across the slit, but all 214 lines of a sweep
pin down one 6-DoF head pose between them. An error in the mirror's homing needs
no parameter of its own: it moves a sweep's lines almost exactly as a small
motion of the head would (a 0.05° offset matches a rigid head correction to
about a micron), so the head pose absorbs it.

### Drawing a Gaussian on a line

This is the 3DGS projection, cut down to one row. Each 3D Gaussian is projected
to a 2D Gaussian on the image plane (the local affine, or EWA, approximation),
widened by the pixel's footprint, and then read off along the row
`v = v_slit`. A 2D Gaussian cut along a line is a 1D Gaussian, so every
(line, Gaussian) pair becomes a 1D splat:

```
S  = J W Σ Wᵀ Jᵀ                        2D covariance before blur, [a b; b c]
S' = S + diag(sigma_u², sigma_v²)       with the pixel and slit footprint
dv = v_slit - mu_v                      how far the Gaussian's centre is off the slit

u*      = mu_u + (b / c') dv            centre along the line
var_u   = det(S') / c'                  width along the line
alpha_0 = opacity * k * exp(-dv² / 2c') peak alpha on the line
k       = sqrt(det(S) / det(S'))        blur spreads alpha out but keeps its total

alpha(p) = min(0.99, alpha_0 * exp(-(p + 0.5 - u*)² / 2 var_u))
```

Pixels are then composited front to back, the same as 3DGS, with the same
cutoffs (skip alpha below 1/255, stop at transmittance 10⁻⁴). The tests check
this against an independent 2D EWA splat with explicit matrices, to 10⁻⁹.

### Spectral features

Each Gaussian stores K features instead of RGB, and a shared basis
(bands × K) turns features into a spectrum. Compositing is linear in the color,
so the renderers composite K channels and apply the basis once per pixel. The
synthetic ground truth uses K = 46 and an identity basis (the features are the
spectrum). Training can use fewer: `splat_train --basis 8` starts from the
starting scene's 8 principal spectra (an eigendecomposition of its spectra,
which K = 8 reproduces to 3·10⁻⁴ rms on the synthetic scene) and then learns
the basis along with the features. Its gradient is a sum over pixels of
dL/dband × feature, one more term in the backward pass. Fewer features means
less memory and less raster work per Gaussian, which is what the Nano needs.

## The CUDA rasterizer

It is the 3DGS tile rasterizer with the image collapsed to rows of tiles. Per
batch of lines:

| Pass | What it does |
|---|---|
| count | one thread per (line, Gaussian) pair: project, keep the pixel range if it reaches the line |
| scan | prefix sums give every visible pair a slot and every (pair, 32-pixel tile) overlap a key slot |
| emit | write the 1D splats and the keys: line and tile in the high 32 bits, depth in the low 32 |
| sort | Thrust radix sort, so each tile's splats come out front to back |
| raster | one warp per (line, tile), one lane per pixel; the warp pulls the tile's splats through shared memory 32 at a time and composites until every pixel is opaque |

Some choices, briefly:

- **Tiles of 32 pixels** make one tile one warp, so the 32 pixels share every
  load and stay in step without any synchronisation beyond the warp's.
- **Features in chunks** of 8 or 16 channels (the grid's y dimension) keep the
  accumulators in registers for any number of bands.
- **Batches of lines** cap the scratch memory: about 12 bytes per
  (line, Gaussian) pair, 200 MB at the default 2²⁴ pairs, which leaves room on
  the Nano's 4 GB shared with the CPU.
- **CUDA 10.2 limits** (JetPack 4.6, sm_53): device code is C++14, scans and
  sorts use Thrust (CUB isn't bundled before CUDA 11), only `float` atomics,
  and warp intrinsics use the `_sync` forms. The host code is C++17 that gcc 7
  builds (so no `std::filesystem`).

For training, `mse_backward()` runs the same passes, then three more: the
loss per pixel (bands, error and dL/dfeatures), the raster pass backwards (one
warp per (line, tile) again, each lane walking its pixel's list back to front
from where the forward pass stopped, the warp summing each splat's gradients
so that it costs one atomic add per value), and the projection backwards (one
thread per visible pair, into the Gaussian and the line's camera). By
default the trainer copies the scene up and the gradients down every step and
keeps Adam on the CPU, which is simple and costs a few MB of copies per step.
On TheRig the GPU's gradients agree with the CPU reference's to about 10⁻⁶
(relative).

With `--gpu-adam` the scene, its Adam moments and densification stay on the
GPU (`src/cuda/optimizer.cu`); only the 128 line cameras go up and their pose
gradients come down. On TheRig that takes a `default` step from 7.1 to 1.9 ms
(the copies were most of it), and 8 features through a learned basis
(`--basis 8`) to 1.1 ms; [`docs/nano_budget.md`](docs/nano_budget.md) has
every preset. Adam and densification run the same code as on the CPU and
give the same scene bit for bit, which the tests check:

- **Adam** uses `__fmul_rn`, `__fadd_rn` and friends, which stop the compiler
  fusing a multiply and an add into one FMA (one rounding instead of two), so
  each value rounds exactly as on the CPU.
- **Densification** needs random offsets for the split Gaussians. Instead of
  one random stream, which only a single thread could walk in order, each
  offset is a hash of (step, Gaussian, axis), so any thread can make its own.
- **New Gaussians go where the CPU puts them**: prefix sums over "kept" and
  "born" flags give each Gaussian its slot in the new arrays.

The tests run both renderers on the same lines and require all but 0.1% of
values to agree to 10⁻⁴ (float rounding can tip a splat across a cutoff).
On a 4-core cloud CPU the reference renders the default dataset (1712 lines ×
256 pixels × 46 bands) in 0.12 s. On TheRig (RTX 4070 SUPER, CUDA 13.4) the
CUDA renderer does it in 2.8 ms of GPU work, or 9.3 ms counting the copy of the
80 MB result back to the CPU, against 40 ms for the reference on the machine's
28-thread i7-14700KF. [`docs/nano_budget.md`](docs/nano_budget.md) works out
what training takes on the Nano, in memory and time per preset, and lists the
commands that measure it there.

## Training

`splat_train` fits a splat to a dataset's lines and refines the sweep poses
at the same time. Each step takes 128 random lines (every line gets a turn
before any repeats), renders them, compares them with the measured lines
(mean squared error over every pixel and band), backpropagates, and takes an
Adam step on the Gaussians and on one pose correction per sweep. The backward
pass is 3DGS's, per pixel and back to front (`backward_cpu.hpp` spells it
out); the tests check every gradient, the pose ones included, against finite
differences in `double`, and the GPU's against the CPU's.

Some choices, briefly:

- **Start on the board.** 3DGS starts from a structure-from-motion point
  cloud, which a line scanner doesn't have. Instead every recorded pixel ray
  is cut with the board's plane (z = 0), and each 1 mm cell the rays land in
  gets a Gaussian with the mean spectrum of their pixels. The ball and the box
  grow out of the board through densification.
- **Densify per line.** 3DGS clones or splits Gaussians whose screen-space
  gradient stays large, averaged per image. Here a Gaussian only gets gradient
  from the lines that cut it, so the average is per (line, Gaussian) pair,
  with the centre measured in line widths so that the threshold doesn't depend
  on the camera's resolution. Small Gaussians are cloned, ones over 1 mm split
  in two, and nearly transparent or oversized ones are pruned.
- **One pose correction per sweep.** A line on its own says almost nothing
  about where it was across the slit, but a sweep's one or two hundred lines
  share one arm pose. Each line camera's pose gradient is carried back to a
  6-DoF correction of its sweep's head pose, made in the camera's frame. A
  mirror homing error needs no parameter of its own, since a small head motion
  moves the lines the same way.
- **No sweep is held fixed.** Pinning one sweep at its recorded pose, the
  usual way to stop the whole reconstruction from drifting, stalls at 1.4 px
  on the 16-sweep scan below (against 0.47 px): that sweep's error is baked
  in, and every Gaussian has to move to match it, which gradient steps do
  badly. With every sweep free, the scene stays where the recorded poses put
  it on average and only their disagreements get corrected.

Results after the default 3000 steps, starting from the recorded poses. The
pose error is how far apart the trained and the true line cameras put points
on the board, in pixels, after the best rigid alignment of the two (moving
everything together changes nothing in the data, so no trainer can recover
it).

| Dataset | Sweeps | Pose error: recorded → trained | Gaussians | Time, 4-core CPU |
|---|---|---|---|---|
| `small` (128 px, 24 bands) | 6 | 5.5 → 1.09 px | 9,994 | 43 s |
| `small --sweeps 16` | 16 | 5.2 → 0.47 px | 12,452 | 54 s |
| `default` (256 px, 46 bands) | 8 | 10.6 → 2.0 px | 11,205 | 101 s |
| `default --sweeps 16` | 16 | 10.9 → 0.97 px | 12,938 | 108 s |

A pixel covers 0.33 mm of the board at 128 px and 0.16 mm at 256 px, so both
16-sweep runs line the sweeps up to about 0.15 mm. Every run renders the
measured lines to about their noise (RMSE 0.015 to 0.019, where the true scene
at the true poses scores 0.016). Runs differ by about 0.01 px from one to the
next, since threads add up the gradients in a different order each time. On
TheRig the 16-sweep runs reach the same pose errors in 10 s (`small`) and
16 s (`default`) on the GPU, and the `small` one in 24 s on the CPU.

Three views of the scene from the overview camera: the true scene, a splat trained from 16 sweeps that matches it closely, and one trained from 8 sweeps, where the ball smears into the board and the checker border doubles.

The true scene (left) and splats trained on the default dataset's lines: from
16 sweeps (middle) and from the default 8 (right). Only what the scans saw
comes back, so the table frays at the edges.

What this says for the rig:

- **Scan many sweeps from all around.** With 6 or 8 sweeps the ball and the
  box are seen from too few directions: the trainer paints them onto the
  board, and each sweep's pose bends to fit its own view. With 16 sweeps the
  pose error is half or less.
- **Some error is the geometry's, not the trainer's.** Holding the true scene
  fixed and refining only the poses stops at about 0.3 px (at 128 px), even
  with noise-free lines and perfect mirror angles. Turning a sweep slightly
  about the board while shifting it to keep the board in place barely changes
  what a narrow fan sees of a flat board, so the loss is nearly flat in that
  direction. A target with textured relief instead of a flat board should
  pin it down better. On the simulator's relief target it doesn't yet: the
  poses come back to about 1.7 px at 256 px, against the board's 0.5, and
  refining them against a fixed relief scene from the logged poses runs away (see
  [Relief or flat board](../pipeline/README.md#relief-or-flat-board-how-well-the-poses-come-back)).
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

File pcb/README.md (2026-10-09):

# PCBs

Two boards, drawn in KiCad 10. Everything else on the rig is a ready-made module, a ribbon or a USB cable.

| Board | What it does | Size | Order with |
|---|---|---|---|
| [Scan-mirror controller](#scan-mirror-controller) | Carries the ESP32-DevKitC and the BTT TMC2209 in sockets, takes 12 V for the mirror's NEMA 8, and has the motor, hall-sensor and Jetson connectors | 95 × 66 mm, 2 layers, 1.6 mm | [`scan_controller/fab/`](scan_controller/fab/) |
| [Hall-sensor breakout](#hall-sensor-breakout) | Holds the A3144 home sensor's leads on the outside of the scanner head and takes its 3-wire cable | 14 × 12.4 mm, 2 layers, 0.8 mm | [`hall_breakout/fab/`](hall_breakout/fab/) |
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

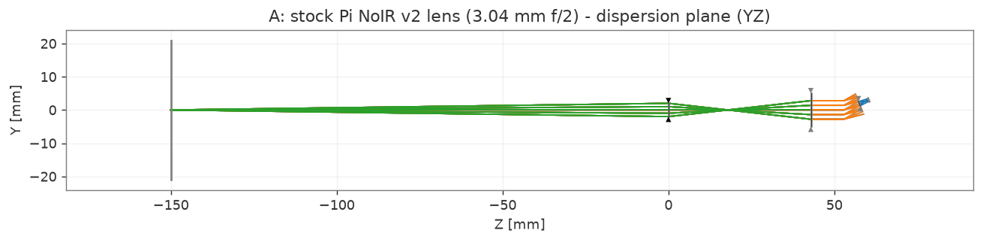
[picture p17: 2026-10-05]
optics/model_output/layout_A_YZ.png

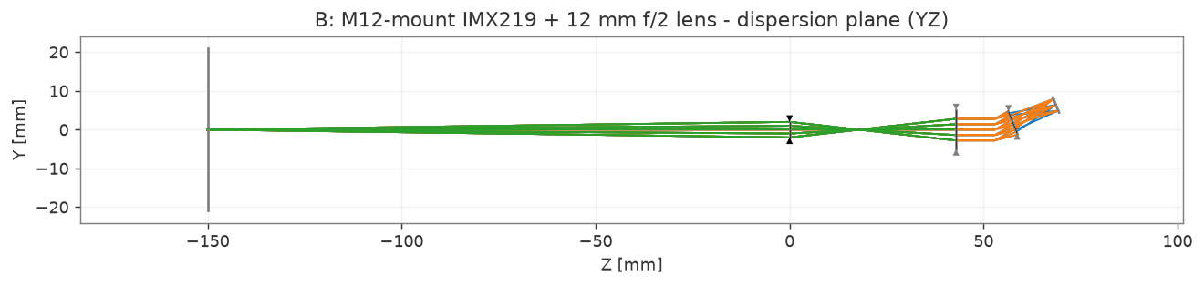
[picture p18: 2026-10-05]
optics/model_output/layout_B_YZ.png

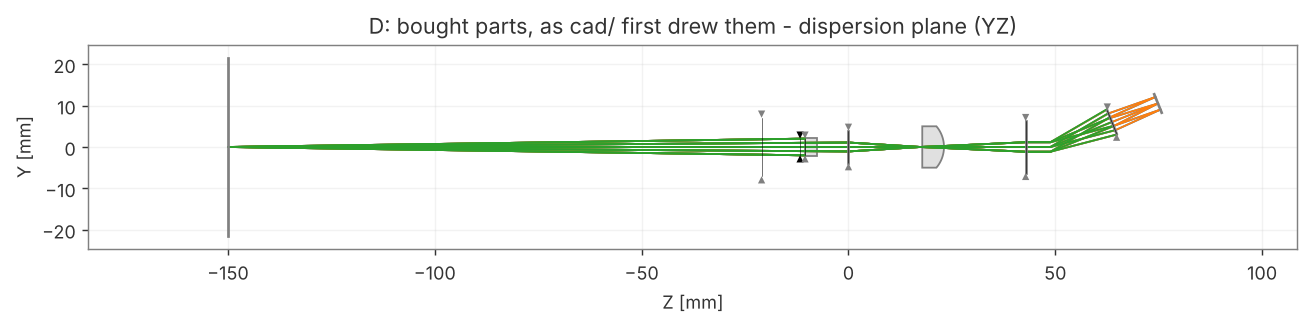
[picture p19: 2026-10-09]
optics/model_output/layout_D_YZ.png

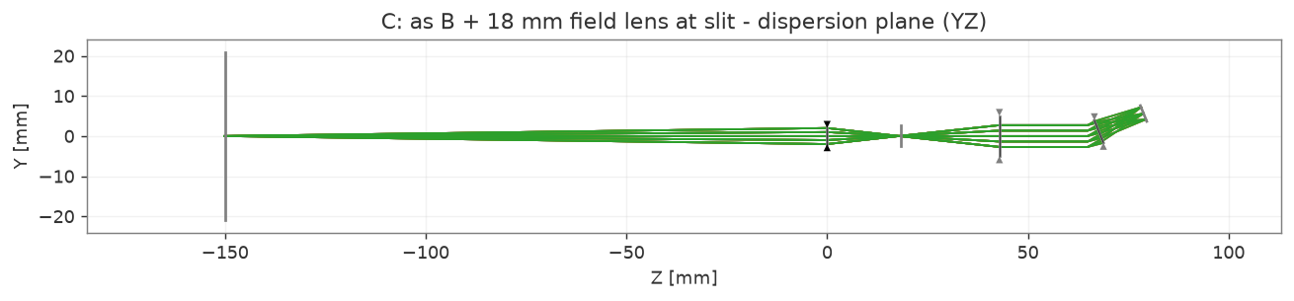
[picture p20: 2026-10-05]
optics/model_output/layout_C_YZ.png

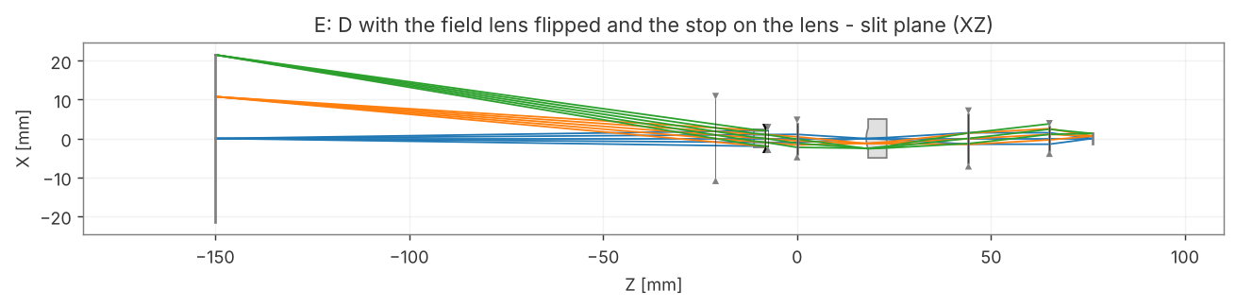
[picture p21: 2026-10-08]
optics/model_output/layout_E_XZ.png

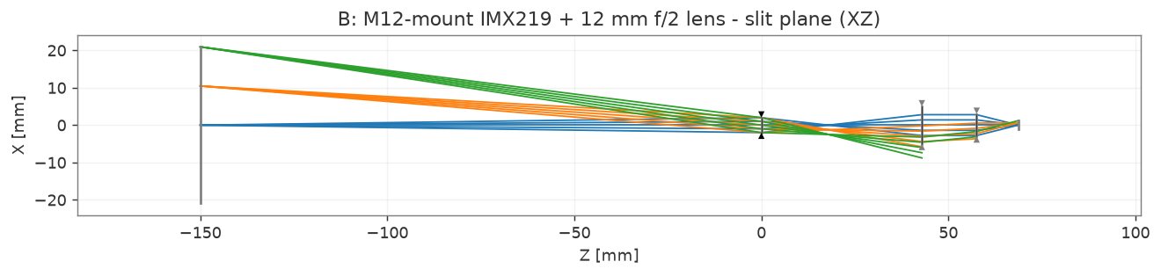
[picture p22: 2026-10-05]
optics/model_output/layout_B_XZ.png

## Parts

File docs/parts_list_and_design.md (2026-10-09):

# Line-scan hyperspectral splatting: parts list and first-order design

Status: parts list updated to what was bought, 2026-10-08. Nothing has arrived yet; the Amazon order and the long-pass filter are due Friday, October 9. Model: `optics/spectrograph_model.py` (Optiland 0.6.2): configs A to C are the design study with ideal lenses, and D and E use the bought parts; `cad/` builds E. Results: `optics/model_output/results.txt` and the layout PNGs. Diagram: `docs/optical_train_v2.svg`.

Section 3 is the bill of materials for this build. Each row names the exact part that was bought or is already owned, with its part number or Amazon ASIN, what it cost and where it stands. The notes keep the earlier generic picks where they help someone building from scratch. Section 6 lists the orders with each listing's full name.

## 1. Design findings from the optical model

The obvious cheap build puts a slit, collimator and grating in front of a stock Raspberry Pi NoIR camera. The Optiland model shows that this doesn't work, and it points to four design rules.

1. **Don't use a camera with a tiny fixed lens.** The Pi NoIR v2's stock lens has a 1.5 mm entrance pupil, while the collimated beam from a 25 mm collimator at f/4 is about 6 mm wide. Only 8% of the light reaches the sensor at the center of the line. At the ends of the line, the light walks off the pupil entirely and 0% gets through. Use an IMX219 NoIR board with an **M12 lens mount** and a 12 mm f/2 lens, which has a 6 mm pupil. It is the same sensor and driver, so it still plugs into a Raspberry Pi or Jetson CSI port.
2. **Put a field lens at the slit.** Without one, the bundles from the ends of the slit leave the collimator at an angle and miss the camera lens, so the line ends get 12–14% of the light. A small lens right behind the slit, with a focal length close to the objective-to-slit distance (17.9 mm), makes the chief rays parallel. Every point on the slit then lands on the same patch of the camera lens, and the line ends get 98–100%. The 15 mm Edmund lens in row 6 does as well in the model: 98% at the line ends.
3. **Plan to calibrate smile and keystone.** Expect about 32 px of smile, meaning one wavelength traces a curve across the sensor rather than a straight row. Conical diffraction at the grating causes it, and every flat transmission grating has it. Expect about 11 px of keystone, meaning the line length changes slightly with wavelength. You calibrate both once with lamp lines, then remap every frame with a warp. Writing that warp as a CUDA kernel makes a good first CUDA exercise.
4. **Turn the field lens's curved side toward the slit.** A plano-convex lens does its bending at its curved face. With the flat side toward the slit, the bought lens acts as if it sat 3.9 mm behind the slit, and from there it magnifies the slit 1.35× for the collimator. That makes the slit image 31 px wide instead of 24 (5.4 nm resolution instead of 4.1), and the image of the 5 mm slit grows to 3.26 mm, longer than the sensor's 2.76 mm side, so 15% of the line falls off the sensor. With the curved side toward the slit it acts from 0.43 mm behind the slit and magnifies 1.03×. Section 2 has the numbers.

| Config (ideal lenses) | Light at line center | Light at line ends | Dispersion | Spectral res. | Pixels along line |
|---|---|---|---|---|---|
| A: stock Pi NoIR v2 lens | 8% | 0% | 1.5 px/nm | 3.7 nm | 543 |
| B: M12 IMX219 + 12 mm lens | 92–100% | 12–14% | 5.8 px/nm | 3.7 nm | 2143 |
| **C: B + 17.9 mm field lens (recommended)** | **100%** | **98–100%** | **5.8 px/nm** | **3.7 nm** | **2204** |

Spectral resolution is the slit image width divided by the dispersion. Both scale with the camera focal length, so resolution depends only on the slit width and the collimator focal length. A 25 µm slit would give about 1.9 nm. In C the slit image is about 21 px wide, so you can bin 4×4 freely, which buys signal-to-noise for free. "3.7 nm" assumes perfect lenses, so expect real M12 lenses to land around 5–8 nm.

The table's slit widths are the paraxial estimate, slit width × 12/25. Tracing the slit's two edges through the grating gives 4.1 nm for C. The beam leaves the grating at 22°, which stretches the slit image 1.08× across the dispersion, and C's thin field lens 0.5 mm behind the slit adds 1.03×. The bought-parts numbers in section 2 are traced the same way.

## 2. Final optical train (config C)

```
scene ──150 mm──► [scan mirror, ~20 mm ahead of the objective, folds the path]
      ► objective: M12 16 mm, stopped to f/4 (4 mm printed washer = aperture stop)
      ──17.9 mm──► slit 50 µm × 5 mm (long axis vertical) + field lens f = 15 mm right behind it
      ──25 mm──► collimator: M12 25 mm used backwards (slit where its sensor would be)
      ──22 mm──► 500 l/mm grating film (grooves parallel to the slit), taped onto the camera lens front
      ──3 mm──► camera lens: M12 12 mm f/2, axis tilted 22° (1st order at 750 nm)
      ──12 mm──► IMX219 NoIR, spectrum along the 3280 px axis (3.27 mm of 3.68 mm used),
                 slit along the 2464 px axis (2.4 mm of 2.76 mm used)
495 nm long-pass filter (SCHOTT GG-495) in front of the objective, in the same cap as the f/4 stop
```

The printed head in `cad/` builds this train with one change at the back end. The camera lens barrel doesn't fit 3 mm from the grating, so the grating sits 6 mm behind the collimator and the camera lens 16 mm behind the grating. The spectrum length, smile and keystone stay the same, but at 500 and 1000 nm the model passes about 60% of the light instead of 100%, and flat-fielding against the white reference evens out the difference. Details are under "Optics as built" in `cad/README.md`.

Scene coverage at 150 mm: the line is 42 mm long and 0.42 mm thick. About 150 lines, spaced one line-thickness apart, cover a 63 mm wide patch.

**Why each piece is there**

- **Objective:** Images the scene onto the slit. Any M12 lens works, as long as it has no IR-cut filter. The f/4 stop matches the beam the camera lens can accept, so a faster lens only adds stray light.
- **Slit:** Picks one line of the scene. Narrower gives better spectral resolution and less light.
- **Field lens:** It steers each bundle so all of them hit the camera lens (rule 2). An ideal thin lens at the slit wouldn't change the focus; the real one is 5.25 mm thick, so the collimator focuses a little further back.
- **Collimator:** Turns each slit point into a parallel beam, so the grating sees one clean angle.
- **Grating:** Spreads wavelength by angle. At 500 l/mm, 500–1000 nm spans 14.5°–30°. The camera sits at 22°.
- **Long-pass filter:** The grating also throws a 2nd order at twice the angle-per-nm. Without the filter, 2nd-order 400–500 nm light lands on top of 1st-order 800–1000 nm.

### With the parts that were bought (configs D and E)

Configs D and E trace the bought parts wherever the vendor publishes enough to model them. The Edmund field lens is real N-BK7 surfaces (R 7.75 mm, 5.25 mm thick). The GG-495 is a 3 mm glass plate, and the printed stop and the 20 × 20 mm mirror are apertures. The objective uses the CIL161's published 15.6 mm focal length. The M12 lenses are still ideal, since Commonlands and Arducam don't publish prescriptions. Both configs use the spacings `cad/` builds, with the grating 6 mm behind the collimator and the camera lens 16 mm behind the grating, and the collimator focused on the slit as the field lens shows it. D puts every part where `cad/` first drew it. E turns the field lens round and moves the stop onto the lens, and it is what `cad/` builds now.

| Traced, ideal M12 lenses | D: as `cad/` first drew it | E: field lens flipped, stop on the lens, as `cad/` builds it |
|---|---|---|
| Field lens faces the slit with its | flat side | curved side |
| Slit as the collimator sees it | 1.35× as big, 0.42 mm further back | 1.03× as big, 1.76 mm further back |
| Collimator principal plane behind the slit | 25.4 mm | 26.8 mm |
| Slit image width | 35 µm (31 px) | 27 µm (24 px) |
| Spectral resolution | 5.4 nm | 4.1 nm |
| Line on the sensor's 2.76 mm side | 3.26 mm, 85% of it on the sensor | 2.56 mm, all of it |
| Scene line at 150 mm that reaches the sensor | 36.5 mm | 43.1 mm |
| Line end used below | the last point on the sensor at every wavelength, 84% of the way to the slit's end | the slit's end |
| Smile / keystone at the line end | 40 / 17 px | 36 / 12 px |
| Light at the line end, 750 nm / 500 nm | 53% / 32% | 54% / 35% |
| RMS spot at the line end | 5 µm | 5 µm |

What the trace decides, part by part:

- **Field lens.** Turn it curved side toward the slit, as in E (rule 4). The lens's principal plane is where it acts as a thin lens. With the flat side first, that plane is 3.47 mm inside the glass (the thickness divided by the glass index, 5.25 / 1.51), so 3.9 mm behind the slit once the 0.43 mm gap between the slit and the lens is added (the 0.38 mm blades plus 0.05 mm of recess). With the curved side first it is at the curved vertex, right behind the blades. Either way the collimator has to sit a little further back than 25 mm, because the slit seen through the glass looks further away: 0.42 mm with the flat side first, 1.76 mm with the curved side first.
- **Objective and stop.** Commonlands lists the CIL161 at 15.6 mm and f/2.0, so the 4 mm printed stop makes it f/3.9 and the line 43 mm long at 150 mm. Keep a 4 mm stop. The CIL122 camera lens's 6 mm pupil only takes about an f/4 beam. Opening the objective to f/2 lets in 3.8 times the light, but only 1.27 times E's center signal reaches the sensor at the line center, and 1.66 times it at the line ends (partly because taking the printed stop away also moves the stop into the lens). Light worth another 2.6 times E's center signal gets through the slit and misses the sensor. That light lands on the walls of the head as stray light, which raises the floor under every spectral line. Where the stop sits matters as much as its size, because the field lens is meant to image the stop onto the camera lens. At the front of the filter cap, 11.7 mm ahead of the objective's principal plane by `cad/`'s estimate, the line ends get 42% of the center's light. A thin washer on the lens's front face (8.1 mm ahead, filter in front of it) gets 54%. The lens's own internal stop would give 95%, but a washer can't go there. A 5 mm washer on the lens face gives 1.14 times E's center signal at the center and 0.76 times at the line ends, but at the ends about as much light again misses the sensor. Printing 4 and 5 mm washers and comparing them on a neon frame at first light is a cheap test.
- **Slit width.** Keep 50 µm, set with the feeler gauge's 0.05 mm leaf. With E that gives 4.1 nm before lens blur. The 0.04 mm leaf gives 3.3 nm for 20% less light. If the field lens stays flat side first, the 0.04 mm leaf brings D back to about 4.3 nm, but the line still overfills the sensor.
- **Camera tilt.** No change with a 500 l/mm grating: the camera axis stays at 22.0°, the 750 nm first-order angle. The sensor's 3.68 mm then covers 460–1022 nm at the line center, so 500–1000 nm fits with about 40 nm to spare at the blue end and 22 nm at the red end, a little less at the line ends, where smile pushes 1000 nm outward. Each degree of tilt error moves the band about 33 nm, so keep the tilt within about −0.5° (a smaller angle, where 1000 nm falls off first) and +1° (a larger angle, where 500 nm falls off first). The pitch of the grating Ryan owns isn't confirmed. A 600 l/mm film would need the camera at 26.7° and would cover only 516–967 nm. A 1000 l/mm film can't work, because 1000 nm would leave it at 90°. A 300 l/mm film fits the band easily but cuts the dispersion to about 0.57 times (3.3 px/nm), giving 6.9 nm.
- **Filter and second order.** SCHOTT's data for 3 mm of GG-495, including the two surface reflections, gives 20% at 490 nm, 67% at 500 nm, 88% at 520 nm and 86–91% from 550 to 1000 nm. The edge is soft, so second-order light from about 485–511 nm still gets through, and it lands on the first-order 970–1022 nm end. Treat the spectrum past about 970 nm with care. A rough estimate puts that light at up to about a tenth of the signal there under a halogen lamp, and more under daylight.
- **Spot sizes.** With ideal M12 lenses the only aberrations left come from the field lens. Spots are about 1 µm RMS at the line center and about 5 µm at the line ends, well under the 27 µm slit image. Real M12 lens blur isn't published and will likely dominate.
- **Scan mirror.** A 20 × 20 mm piece clears the beam with room to spare: taking the mirror out of the model changes no number.

`cad/` has built config E since October 9. The slit block seats the field lens curved side toward the blades, the collimator sits 26.76 mm behind the slit with everything behind it moved back to match, and a 0.6 mm washer with a 4 mm hole sits on the objective's front face. [`cad/optics_as_built.txt`](../cad/optics_as_built.txt) traces the head as drawn. There the washer sits 8.5 mm ahead of the objective's principal plane instead of E's 8.1 mm, which still gives 4.1 nm and 52% of the center's light at the line ends at 750 nm.

## 3. Parts list

Statuses as of 2026-10-08: **ordered** (paid, not arrived), **owned** (Ryan's own stock), **to buy**, **unconfirmed** (owned, but a detail still needs checking). Paid prices come from the order confirmations, before tax. Prices marked ✓ on parts still to buy were read on the seller's page on October 6 or 7.

### 3.1 Spectrograph optics

| # | Part | Bought | Paid | Status | Notes |
|---|---|---|---|---|---|
| 1 | Spectrograph camera | Arducam **B0152** NoIR 8 MP IMX219 M12-mount board, from [Arducam's store](https://www.arducam.com/arducam-raspberry-pi-camera-module-v2-8mp-imx219-m12-noir-picam-b0152.html) | $35.00 | ordered, express | No IR-cut filter, 36 × 36 mm, 15-pin CSI. Its stock 1.8 mm LS1820 lens comes off for row 2. The same board is on RobotShop as the LS1820 listing. Avoid Arducam B0183, which has a fixed IR-cut filter. |
| 2 | Camera lens, 12 mm f/2 | Commonlands **CIL122-F2.0-M12ANIR**, [IR Corrected 12mm M12 Lens, F/2.0, Without Filter](https://commonlands.com/products/ir-corrected-12mm-m12-lens) | $59.00 | ordered | First ordered as the -M12A650 version with a 650 nm IR-cut filter; Commonlands swapped it to no filter on October 7 at the same price. Look into the back on arrival: a pink or blue-green tint means the IR-cut version came anyway. Budget alternative: Arducam LN065, $12.99; its listing doesn't say whether it has an IR-cut filter, so check it the same way on arrival. |
| 3 | Objective, 16 mm f/2 | Commonlands **CIL161-F2.0-M12ANIR**, [IR Corrected 16mm M12 Lens, F/2.0, Without Filter](https://commonlands.com/products/ir-corrected-16mm-m12-lens-cil161) | $39.00 | ordered | Swapped from -M12A650 the same way. Commonlands lists its focal length as 15.6 mm. The 4 mm printed stop makes it f/3.9 (section 2). Avoid Arducam LN001, which has a 650 nm IR-cut filter. |
| 4 | Collimator, 25 mm f/2 | Arducam **LN016** (lens M2025ZH01), 1/2" format, no IR filter, from [Arducam's store](https://www.arducam.com/m2025zh01-m12-mount-25mm-focal-length-camera-lens-mtv2520b-for-raspberry-pi-camera.html) | $17.99 | ordered, express | 17 × 21 mm, 12.5 mm aperture. Back focus isn't published, and a sibling Arducam 25 mm lens lists 5.2 mm, so measure it. |
| 5 | M12 holders ×2 (objective, collimator) | uxcell 10-pack, 20 mm screw spacing, Amazon [B00R1J42T8](https://www.amazon.com/dp/B00R1J42T8) | $7.79 | ordered, due Oct 9 | Plastic and 14 mm tall: cut two down to the lens thread + 1 mm, as in step 1 of the [Assembly](../cad/README.md#assembly). From scratch: UCTRONICS U0756M10 metal holders. |
| 6 | Field lens, f = 15 mm | Edmund Optics **#49-840**, [12.7 mm dia. × 15.0 mm FL, uncoated plano-convex](https://www.edmundoptics.com/p/127mm-dia-x-150mm-fl-uncoated-plano-convex-lens/10312/), N-BK7, CT 5.25 mm | $32.75 + $9.99 ground shipping | ordered, 1–7 business days | Turn its curved side toward the slit (section 2). The slit block in `cad/` holds it that way. |
| 7 | Slit, 50 µm | 9 mm snap-off blades, 25-pack, Amazon [B0FKTN8WJZ](https://www.amazon.com/dp/B0FKTN8WJZ), set apart with the 0.05 mm leaf of a Spurtar 32-blade feeler gauge set, Amazon [B081SYZ1YV](https://www.amazon.com/dp/B081SYZ1YV) | $4.49 + $4.97 | ordered, due Oct 9 | Two 20 mm pieces of blade. Set the gap with the leaf, glue the blades, and pull the leaf out once the glue sets. The blade thickness isn't listed and `cad/` assumes 0.38 mm, so measure one. The 0.04 mm leaf gives a 40 µm slit. Single-edge razor blades don't fit the printed head. The lab-grade option is in row 32. |
| 8 | Grating, 500 l/mm | Ryan's own diffraction gratings | — | unconfirmed | Pitch not confirmed. If none is 500 l/mm, buy Rainbow Symphony 500 l/mm slides, Amazon [B00PBFTQMM](https://www.amazon.com/dp/B00PBFTQMM), $15.60 ✓. Other 500 l/mm film: Edmund #54-509 ($19.75 ✓) or a [Bartovation sheet](https://bartovation.com/product/other-lab-supplies/diffraction-grating-sheets/500-lines-mm-linear-diffraction-grating-sheet/) ($12.38 ✓). Section 2 says what other pitches do. |
| 9 | Long-pass filter, 495 nm | Edmund Optics **#54-652**, [GG-495 12.5 mm dia. longpass filter](https://www.edmundoptics.com/p/gg-495-125mm-dia-longpass-filter/11321/), SCHOTT GG495, 3 mm | $37.00 | ordered, due Oct 9 | Blocks 2nd-order light; its soft edge passes 67% at 500 nm and 88% at 520 nm (section 2). It sits in the head's filter cap. For a bench build without the head, any 530 nm screw-in filter does the same job. The lab-grade option is in row 32. |
| 10 | Scan mirror | RUEHALF 100 × 100 × 3 mm front-surface mirror, Amazon [B0GW4WT69F](https://www.amazon.com/dp/B0GW4WT69F), cut to 20 × 20 mm with a glass scorer | $20.90 | ordered, due Oct 9 | Score the bare back, not the coated face. Keep the side across the shaft at 20 mm or just under; along the shaft, 20 to 25 mm fits the clamp. Edmund's precut #43-872 ($31.00) was backordered. A rear-surface mirror would create ghost lines. |

### 3.2 Scanning, electronics, lighting, calibration

| # | Part | Bought | Paid | Status | Notes |
|---|---|---|---|---|---|
| 11 | Mirror stepper, NEMA 8 | StepperOnline **8HS11-0204S** (1.8°, 0.2 A, 20 × 20 × 28 mm, 60 g, 4 mm D-cut shaft, M2 holes on 16 mm), Amazon [B00PJYL6BY](https://www.amazon.com/dp/B00PJYL6BY), sold by StepperOnline | $24.48 | ordered, due Oct 9 | At 1/32 microstepping, one microstep moves the line 0.29 mm at 150 mm. On the arm the small motor keeps the head at 185 g instead of 278 g with a NEMA 17, which takes the shoulder servo from 94% to 74% of stall with the arm stretched out. Measure how deep its M2 holes are threaded: the M2 × 5 screws need 3.2 mm, or file 1 mm off four of them. |
| 12 | Stepper driver | BIGTREETECH **TMC2209 V1.3**, Amazon [B07ZPYKL46](https://www.amazon.com/dp/B07ZPYKL46) | $17.47 | ordered, due Oct 9 | Quiet, and set over UART. It ships at VREF ≈ 1.2 V (0.85 A): turn it to about 0.28 V (0.2 A) with the motor unplugged before the first run ([pcb/README.md](../pcb/README.md#before-the-first-power-up)). From scratch: Adafruit #6121 breakout. |
| 13 | Microcontroller | Ryan's own ESP32 dev board | — | unconfirmed | Runs the [mirror firmware](../firmware/). The controller board's socket is for the 38-pin ESP32-DevKitC with rows 25.4 mm apart, so check the pin count and row spacing before ordering it. From scratch: Espressif ESP32-DevKitC-32E, ~$10. |
| 14 | Stepper power supply | ALITOVE 12 V 3 A adapter, 5.5 × 2.1 mm, with a screw-terminal jack adapter, Amazon [B07VQGHSWY](https://www.amazon.com/dp/B07VQGHSWY) | $9.97 | ordered, due Oct 9 | The NEMA 8 draws only about 0.2 A per phase. |
| 15 | Home switch | Gikfun A3144 hall sensors, 20-pack, Amazon [B07QS6PN3B](https://www.amazon.com/dp/B07QS6PN3B), and one of Ryan's own Ø5 × 1.6 mm disc magnets | $7.58 | ordered, due Oct 9; magnets owned | Gives each scan an absolute start angle. The clamp's magnet pocket is cut for 1.6 mm magnets. The A3144 switches on one pole only, so glue the magnet with the face that trips it facing out. |
| 16 | Controller boards | Scan-mirror controller and hall-sensor breakout, KiCad in [`pcb/`](../pcb/) | not priced | to order | They replace the breadboard wiring. Parts and the JLCPCB order steps are in [pcb/README.md](../pcb/README.md#parts). For breadboard tests: Ryan's breadboard, jumpers, two 10 kΩ, one 1 kΩ and a 100 µF 25 V capacitor (owned, unconfirmed). |
| 17 | Lights | HDX 250 W portable halogen work light, LG351-250W, [Home Depot 334046804](https://www.homedepot.com/p/HDX-250-Watt-Portable-Halogen-Work-Light-LG351-250W/334046804) | $17.98 ✓ | to buy, unless owned | LEDs have almost no output past 700 nm, and you need the NIR. A second light evens out shadows. Skip "cool-beam" GU10 and MR16 bulbs, whose reflectors send the NIR out the back. |
| 18 | Wavelength calibration | EcoSmart 13 W CFL daylight 4-pack, ESL13T2-5K-4-ESM, [Home Depot 313261174](https://www.homedepot.com/p/60-Watt-Equivalent-A19-Spiral-Non-Dimmable-E26-Medium-Base-CFL-Compact-Fluorescent-Light-Bulb-Daylight-5000K-4-Pack-ESL13T2-5K-4-ESM/3132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), and a Sperry GFI6302N outlet tester, [Home Depot 301961462](https://www.homedepot.com/p/Sperry-GFCI-Outlet-Tester-GFI6302N/301961462) | $9.97 ✓ + $14.50 ✓ | to buy, unless owned | The CFL's mercury and phosphor give 546, 578 and 611 nm. The tester's lamps are neon, about 585–880 nm, and it is the safe way to run neon off the wall. Any fluorescent bulb, or any tester whose lamps glow orange, works. |
| 19 | Alignment laser and keystone wires | Ryan's red diode lasers; 3 to 5 thin wires, 0.1 to 0.3 mm (guitar string, magnet wire or a hair) | — | lasers owned; wires unconfirmed | The laser aligns the optical axis and is the calibration kit's last check. It isn't a wavelength reference, because a diode drifts a few nm as it warms. The wires mark points along the slit for the keystone fit ([calibration kit](../calibration/README.md#what-you-need)). |
| 20 | White reference | Sasylvia virgin PTFE sheet, 12 × 6 in, 1/16 in thick, Amazon [B0GKGHX1W6](https://www.amazon.com/dp/B0GKGHX1W6) | $11.99 | ordered, due Oct 9 | Flat-field and reflectance reference. At 1.6 mm it lets some light through, so cut it in half and stack the halves, or back it with white card. |
| 21 | Housing and stray-light lining | The head in `cad/`, printed in black PETG on Ryan's printer; Protostar Hi-tack flocking is optional ($7.50 ✓) | — | owned printer | Some black filaments look grey in NIR, so check a test print through a NoIR camera. Stray light is the main enemy. |
| 22 | Screws and heat-set inserts | HEXPHANT M2 × 5 socket head, 50-pack, Amazon [B0GCT7TQCH](https://www.amazon.com/dp/B0GCT7TQCH); VGBUY 440-piece M3 kit, 25–45 mm, with nuts and washers, Amazon [B0D1XQCJPR](https://www.amazon.com/dp/B0D1XQCJPR); Pofsnnx 350 heat-set inserts, M2–M6, Amazon [B0FVKYJ83G](https://www.amazon.com/dp/B0FVKYJ83G) | $6.19 + $7.99 + $9.99 | ordered, due Oct 9 | The head's full hardware list is in [`cad/README.md`](../cad/README.md). The M3 kit starts at 25 mm, so the four M3 × 6 and three M3 × 8 come from row 23 or a parts bin. Insert holes in `cad/` are sized for these inserts (M2 2.85 mm, M3 4.5 mm). |
| 23 | Short M3 screws | VGBUY 600-piece M3 kit, 6–30 mm, Amazon [B0D1XJ766V](https://www.amazon.com/dp/B0D1XJ766V) | $9.99 ✓ | to buy, unless the bin has them | For the M3 × 6 and M3 × 8. |
| 24 | Glue and tape | Loctite Super Glue Gel Control, Amazon [B0006HUJCQ](https://www.amazon.com/dp/B0006HUJCQ); ½ in × 33 m polyimide (Kapton) tape, Amazon [B0DZCR4TKM](https://www.amazon.com/dp/B0DZCR4TKM) | $3.82 + $5.35 | ordered, due Oct 9 | Glue for the magnet, mirror and slit blades, tape for the grating film. Cure CA in open air: its fumes can haze the mirror. |

### 3.3 Compute, cameras and cables

| # | Part | Bought | Paid | Status | Notes |
|---|---|---|---|---|---|
| 25 | GPU computer (capture + CUDA splat renderer) | Ryan's Jetson Nano 4 GB developer kit | — | unconfirmed | The B01 board has a second camera port for the pose camera; the A02 has one. Which one isn't confirmed. The Nano is stuck on JetPack 4.6 (Ubuntu 18.04, CUDA 10.2), so ROS 2 runs in Docker ([`jetson/`](../jetson/)). From scratch: Jetson Orin Nano Super Developer Kit, $399 (NVIDIA raised it from $249 in July 2026), or a desktop GPU for training and a Raspberry Pi for capture. |
| 26 | Storage | The Nano's microSD card | — | owned, unconfirmed | From scratch: 64 GB microSD, ~$10, or a 256 GB NVMe SSD on an Orin Nano. |
| 27 | Spectrograph camera cable | Arducam 100 cm 15-pin ribbon, Amazon [B087FDJ2RP](https://www.amazon.com/dp/B087FDJ2RP), sold by UCTRONICS | $5.38 | ordered, due Oct 9 | Reaches from the head along the arm. Add strain relief where the arm bends. An Orin Nano or Pi 5 needs a 15-to-22-pin cable instead. |
| 28 | Pose camera cable | A second Arducam 100 cm ribbon, Amazon [B087FDJ2RP](https://www.amazon.com/dp/B087FDJ2RP) | $5.38 ✓ | to buy | |
| 29 | Pose camera | Ryan's Raspberry Pi NoIR camera v2 (IMX219) | — | owned | Reads the AprilTag board, which needs no color. IMX219 works natively on Jetson; the Camera Module 3 (IMX708) doesn't without extra drivers. |

### 3.4 Viewpoints

| # | Part | Bought | Paid | Status | Notes |
|---|---|---|---|---|---|
| 30 | Robot arm | Ryan's LeRobot SO-101 follower arm | — | owned | The scanner head replaces the gripper on the wrist-roll horn ([`cad/`](../cad/)). Pose comes from the tag board, not the arm, so a tripod moved by hand also works. From scratch: SO-ARM101 follower only (PartaBot, $299 ✓, sold out when checked) or the Seeed SO-ARM101 Pro motor kit ($277.99 ✓, no printed parts). |
| 31 | Tag board | AprilTag grid, printed and glued to foam board | ~$5 | to make | Gives one pose per viewpoint, then splatting refines it. |

### 3.5 Optional test gear

| # | Part | Bought | Paid | Status | Notes |
|---|---|---|---|---|---|
| — | Scope / logic analyzer | Ryan's Digilent Analog Discovery 3 | — | owned | Checks the camera exposure strobe against the mirror step timing. |
| 32 | Lab-grade slit and filter | Thorlabs **S50LK** (Ø1" mounted slit, 50 µm × 10 mm) and **FELH0500** (Ø25 mm long-pass) | — | not bought | About $100 each. They replace rows 7 and 9 on a bench build, but neither fits the printed head. Don't buy the S50RD slit, which is only 3 mm long. |

### 3.6 Totals

| Order | What | Paid |
|---|---|---|
| Amazon, due October 9 | Rows 5, 7, 10, 11, 12, 14, 15, 20, 22, 24 and 27 | $148.36 |
| Arducam's store, express | Rows 1 and 4, plus $47.00 express shipping | $99.99 |
| Commonlands | Rows 2 and 3, plus a $9.80 tariff fee; free shipping | $107.80 |
| Edmund Optics | Rows 6 and 9 | $69.75, plus $9.99 shipping on the field lens and tax |
| **Ordered** | | **$425.90** before tax and Edmund's shipping |
| Still to buy | Rows 23 and 28 from Amazon ($15.37); the lamps in rows 17 and 18 from Home Depot ($42.45) | about $58 |
| Only if needed | The grating in row 8 ($15.60), a second halogen light ($17.98), flocking ($7.50) | |

The controller boards in row 16 aren't priced yet. Everything else comes from Ryan's own stock. The first version of this list, on October 5, priced a from-scratch build at roughly $1,200 with generic parts, or about $525 with budget picks and a tripod instead of the arm. The bench spectrometer stage (build step 1 below) needs only rows 1–2 and 4–9, the lamps in row 18, the laser in row 19, the housing in row 21, and a Raspberry Pi or Jetson to read the camera.

## 4. Build order

1. **Bench spectrometer.** Build the slit, field lens, collimator, grating and camera with no objective, pointed at the neon and CFL lamps. Fit the wavelength map and the smile/keystone warp. This is where you learn alignment.
2. **Line imager.** Add the objective and focus it on a printed target. Measure the line thickness on a knife edge.
3. **Scanner.** Add the mirror and stepper. Scan a flat Macbeth-style color card, then assemble the 2D datacube on the GPU (first CUDA kernel: warp + bin).
4. **3D.** Capture from several viewpoints (arm or tripod), get poses from the AprilTag board, and train the splat with the line-camera renderer.
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

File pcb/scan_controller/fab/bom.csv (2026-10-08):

Designator | Value | Footprint | Qty | LCSC | MPN | Assembly | DNP
C1 | 100uF 25V | rig:CP_Radial_D6.3mm_P2.50mm | 1 |  | 100 uF 25 V or 35 V electrolytic, 6.3 mm, 2.5 mm pitch | hand
C2 | 100nF | rig:C_0805_2012Metric | 1 | C49678 | YAGEO CC0805KRX7R9BB104 | JLC
C3 | 1nF | rig:C_0805_2012Metric | 1 | C46653 | Samsung CL21B102KBCNNNC | JLC | DNP
D1 | SS34 | rig:D_SMA | 1 | C8678 | MDD SS34 | JLC
D2 | SMAJ15A | rig:D_SMA | 1 | C113958 | MDD SMAJ15A | JLC
D3 | green | rig:LED_0805_2012Metric | 1 | C2297 | Hubei KENTO KT-0805G | JLC
D4 | red | rig:LED_0805_2012Metric | 1 | C84256 | NATIONSTAR NCD0805R1 | JLC
F1 | 500mA | rig:Fuse_1812_4532Metric | 1 | C492015 | PTTC SMD1812P050TF/30 | JLC
J1 | 12V 5.5x2.1 | rig:BarrelJack_Horizontal | 1 |  | DC-005 style 5.5 x 2.1 mm jack, 3 pins | hand
J2 | 12V | rig:TerminalBlock_Phoenix_MKDS-1,5-2-5.08_1x02_P5.08mm_Horizontal | 1 |  | 2-pin screw terminal, 5.08 mm (KF301-5.08 or Phoenix MKDS 1,5/2-5,08) | hand
J3 | NEMA 8 | rig:JST_XH_B4B-XH-A_1x04_P2.50mm_Vertical | 1 | C144395 | JST B4B-XH-A(LF)(SN) | hand
J4 | A3144 | rig:JST_XH_B3B-XH-A_1x03_P2.50mm_Vertical | 1 | C144394 | JST B3B-XH-A(LF)(SN) | hand
J5 | Jetson | rig:PinHeader_1x03_P2.54mm_Vertical | 1 |  | 1x3 pin header, 2.54 mm | hand
R1,R2 | 10k | rig:R_0805_2012Metric | 2 | C17414 | UNI-ROYAL 0805W8F1002T5E | JLC
R3,R4,R8 | 1k | rig:R_0805_2012Metric | 3 | C17513 | UNI-ROYAL 0805W8F1001T5E | JLC
R5,R6 | 220 | rig:R_0805_2012Metric | 2 | C17557 | UNI-ROYAL 0805W8F2200T5E | JLC
R7 | 4.7k | rig:R_0805_2012Metric | 1 | C17673 | UNI-ROYAL 0805W8F4701T5E | JLC
U1 | ESP32-DevKitC (38-pin) | rig:ESP32-DevKitC_Socket | 1 |  | 2x female header 1x19, 2.54 mm (ESP32-DevKitC plugs in) | hand
U2 | BTT TMC2209 V1.3 | rig:StepStick_Socket_BTT_TMC2209 | 1 |  | 2x female header 1x8, 2.54 mm (driver plugs in) | hand

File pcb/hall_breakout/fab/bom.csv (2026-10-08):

Designator | Value | Footprint | Qty | LCSC | MPN | Assembly | DNP
C1 | 100nF | rig:C_0805_2012Metric_Pad1.18x1.45mm_HandSolder | 1 | C49678 | YAGEO CC0805KRX7R9BB104 | JLC
J1 | to controller J4 | rig:Wire_Pads_1x03_P2.54mm | 1 |  | 3-wire cable soldered in (or a 1x3 pin header) | hand
U1 | A3144 | rig:A3144_UA_Leads | 1 |  | Allegro A3144 (Gikfun), UA package | hand

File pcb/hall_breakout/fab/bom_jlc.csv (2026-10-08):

Comment | Designator | Footprint | LCSC Part #
100nF | C1 | C_0805_2012Metric_Pad1.18x1.45mm_HandSolder | C49678

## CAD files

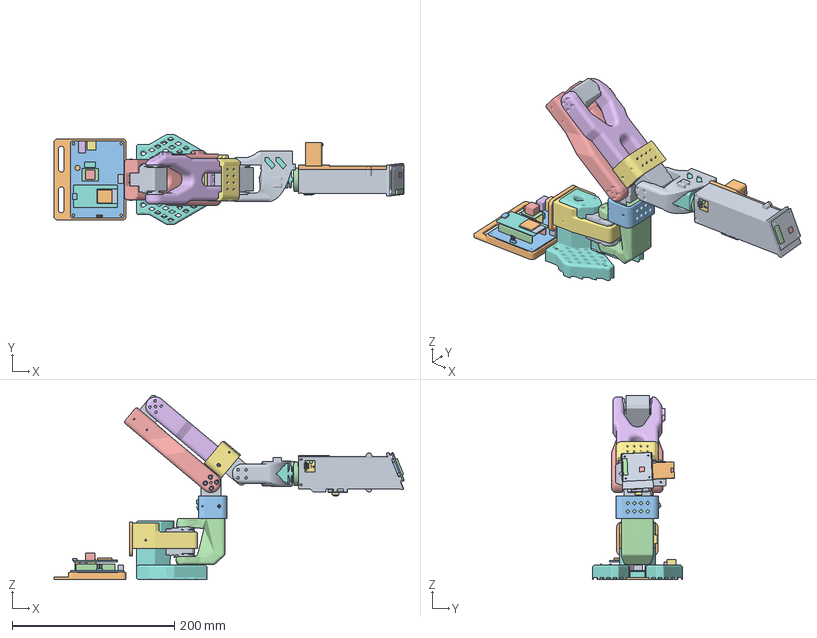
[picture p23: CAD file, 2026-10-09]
cad/so101_hsi_rig.FCStd
431.2 x 110.9 x 227.0 mm
Housing
Lid
Mirror clamp
Wrist puck
Objective carrier
Slit block
Grating carrier
Filter cap
Stop washer, 4 mm001
stepper_housing
stepper_boss
stepper_shaft
stepper_strain_relief
mirror_glass
magnet_disc
hall_body
hall_leg0
hall_lead0
hall_leg1
hall_lead1
hall_leg2
hall_lead2
hallpcb_pcb
hallpcb_m2_head
hallpcb_m2_shank
hallpcb_c1
hallpcb_wire0
hallpcb_wire1
hallpcb_wire2
filter_disc
HSI_objective_thread
HSI_objective_barrel
HSI_objective_front_glass
HSI_objective_rear_glass
HSI_obj_holder_holder
blade_upper
blade_lower
field_lens_lens
HSI_coll_holder_holder
HSI_collimator_thread
HSI_collimator_barrel
HSI_collimator_front_glass
HSI_collimator_rear_glass
grating_film
HSI_cam_lens_thread
HSI_cam_lens_barrel
HSI_cam_lens_front_glass
HSI_cam_lens_rear_glass
cam_pcb
cam_sensor
cam_holder
cam_fpc_connector
cam_bridge_ic
posecam_pcb
posecam_lens_module
posecam_lens
posecam_fpc_connector
Controller tray
ctl_pcb
ctl_devkit_header0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

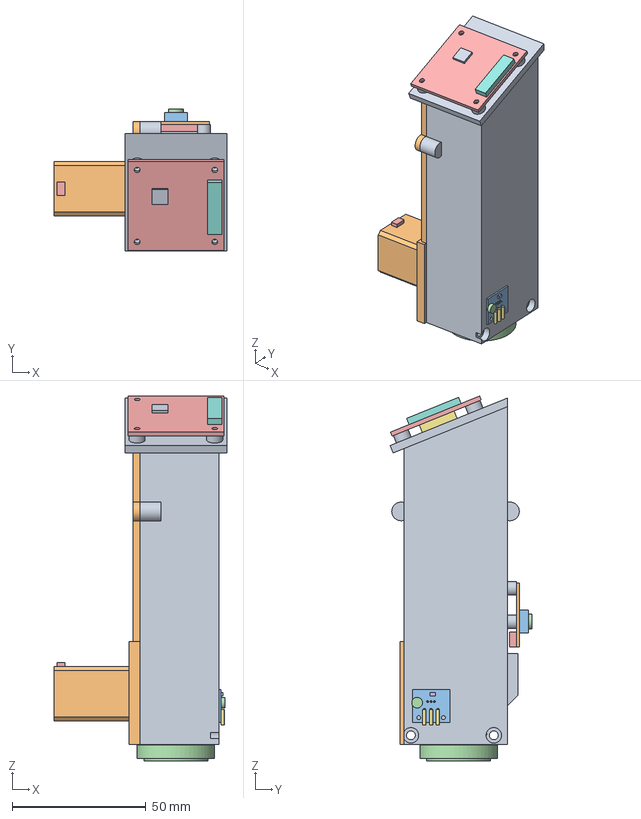
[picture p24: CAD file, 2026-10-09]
cad/step/hsi_head.step
64.5 x 53.0 x 136.4 mm
Housing (printed)
Lid with motor mount (printed)
Mirror clamp (printed)
Wrist puck with dovetail rail (printed)
Objective carrier (printed)
Slit block (printed)
Grating carrier (printed)
Filter cap (printed)
Stop washer, 4 mm
Stepper 8HS11-0204S (NEMA 8, 1.8 deg, 60 g)
Scan mirror: 20 x 20 mm cut from a RUEHALF 3 mm front-surface sheet
Home magnet 5 x 1.6 mm
A3144 hall sensor (home switch)
Hall-sensor breakout (pcb/hall_breakout)
Long-pass filter: Edmund #54-652, GG-495, 12.5 mm
Objective: Commonlands CIL161 15.6 mm (4 mm stop)
M12 holder: uxcell, cut down (objective)
Slit: two snap-off blade pieces, 50 um gap
Field lens: Edmund #49-840, PCX 12.7 mm, f = 15 mm
M12 holder: uxcell, cut down (collimator)
Collimator: Arducam LN016 25 mm (reversed)
Grating film 500 l/mm (grooves along X)
Camera lens: Commonlands CIL122 12 mm
Arducam B0152 IMX219 NoIR (M12)
Pose camera: Pi NoIR v2 (owned)

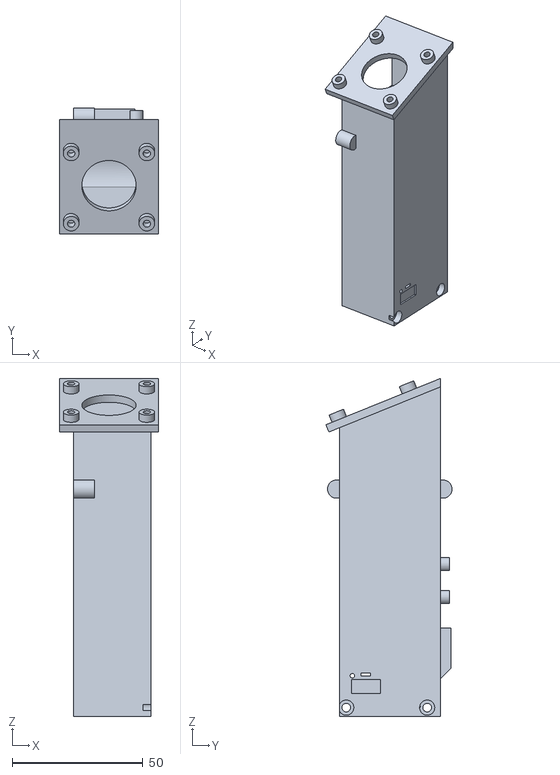
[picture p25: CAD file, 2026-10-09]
cad/stl/housing.stl
38.0 x 48.3 x 129.4

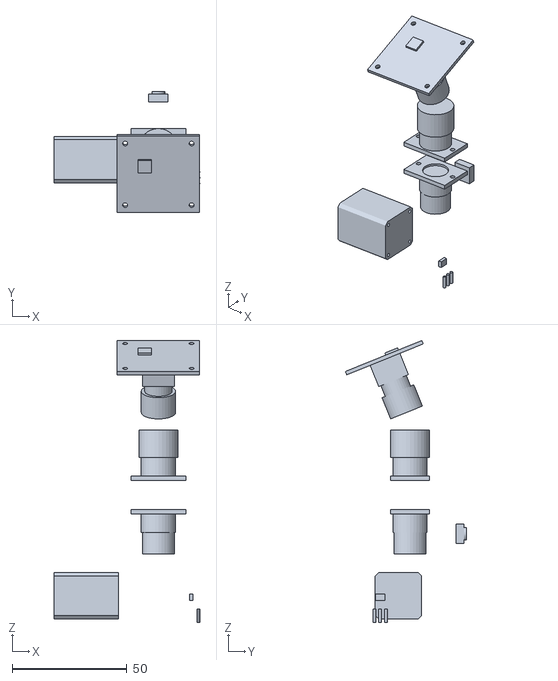
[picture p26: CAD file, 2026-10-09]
ros2/so101_scan_description/meshes/scan_head/head_dark.stl
63.6 x 52.9 x 123.0

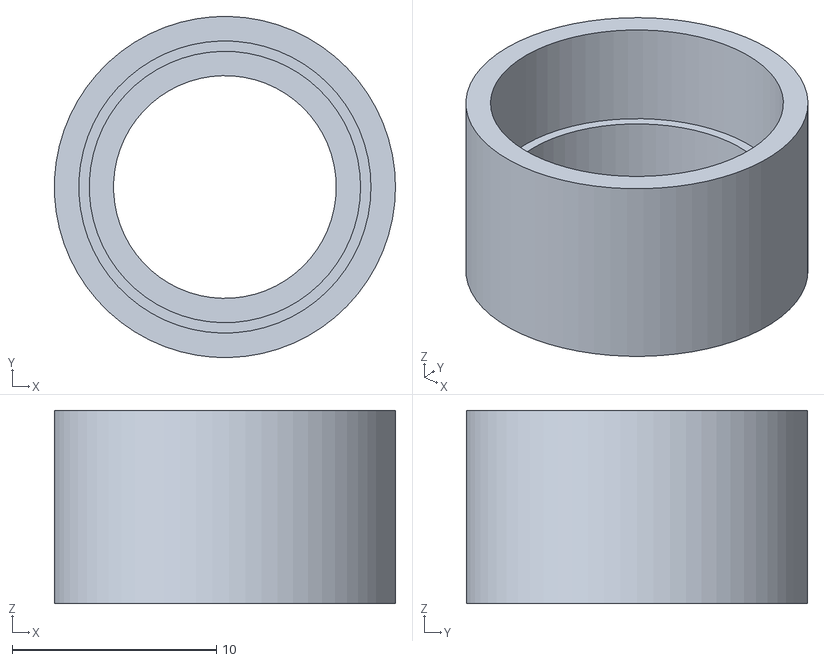
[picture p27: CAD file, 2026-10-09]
cad/stl/filter_cap.stl
16.7 x 16.7 x 9.45

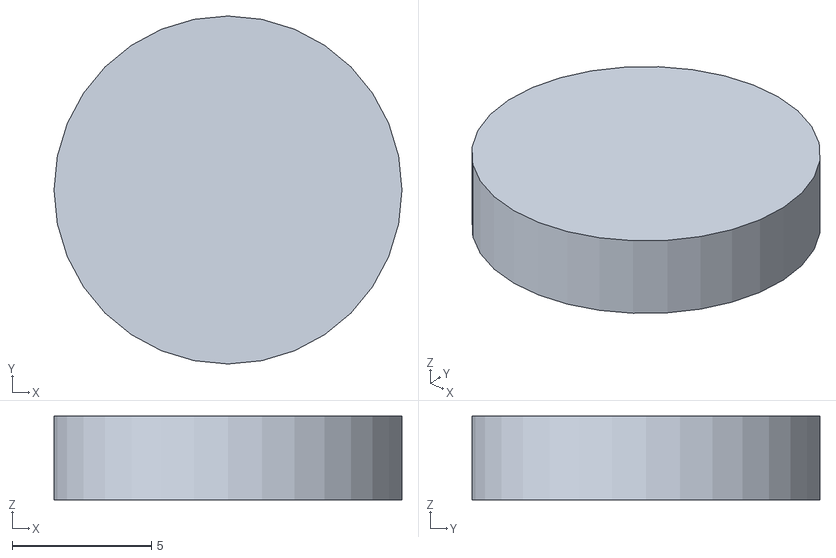
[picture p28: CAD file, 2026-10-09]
ros2/so101_scan_description/meshes/scan_head/head_filter.stl
12.5 x 12.5 x 3.00

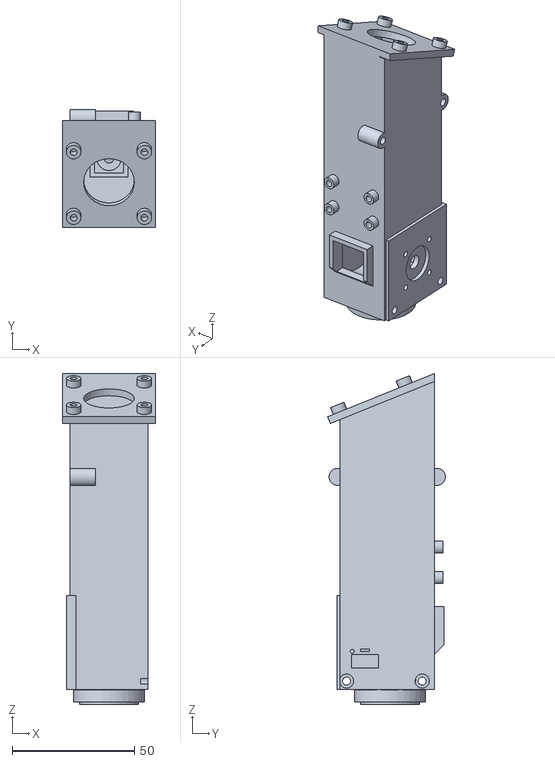
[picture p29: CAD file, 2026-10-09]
ros2/so101_scan_description/meshes/scan_head/head_printed.stl
38.0 x 48.3 x 135.6

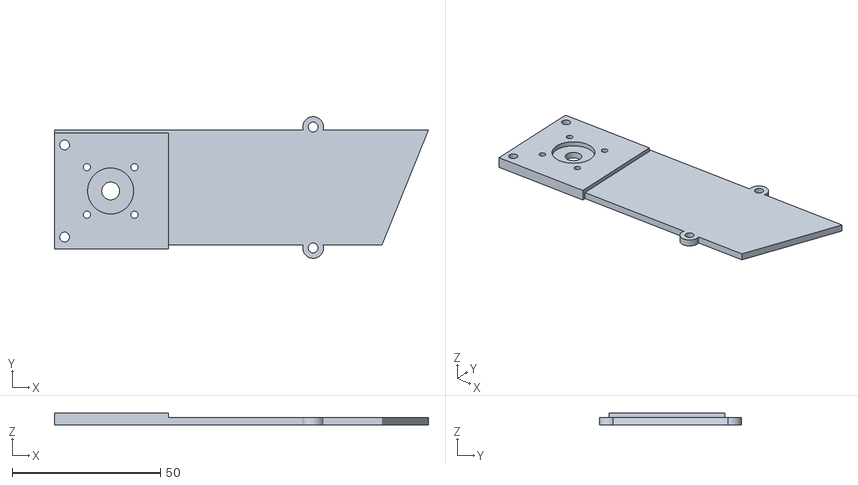
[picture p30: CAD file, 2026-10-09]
cad/stl/lid.stl
125.9 x 47.7 x 4.00

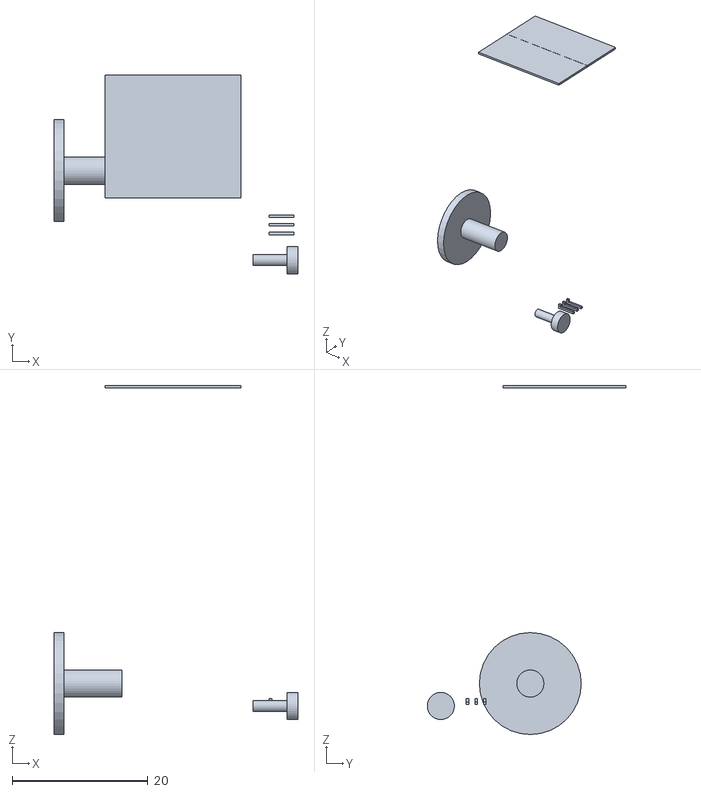
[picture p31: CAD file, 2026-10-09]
ros2/so101_scan_description/meshes/scan_head/head_metal.stl
35.9 x 29.2 x 51.4

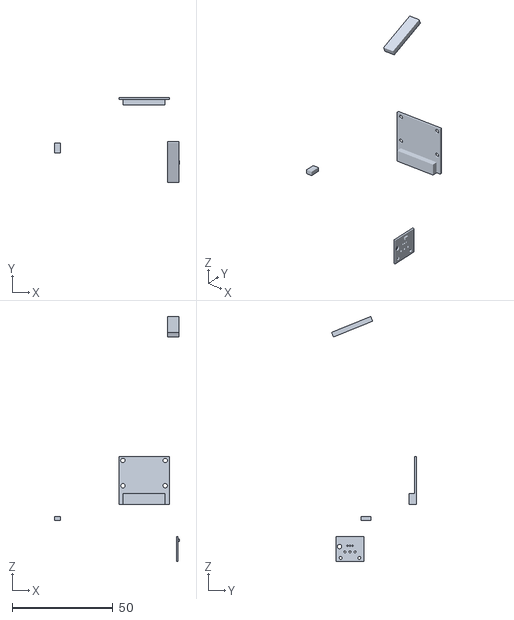
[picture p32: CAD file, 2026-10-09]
ros2/so101_scan_description/meshes/scan_head/head_pcb.stl
62.1 x 42.2 x 121.5

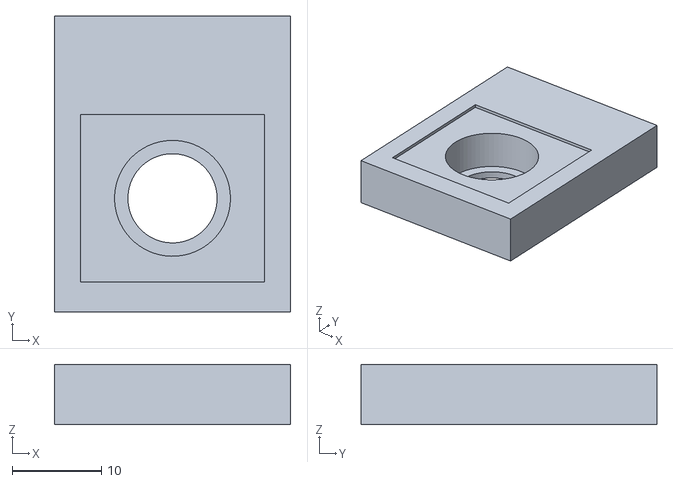
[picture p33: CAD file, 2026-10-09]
cad/stl/slit_block.stl
26.5 x 33.2 x 6.76

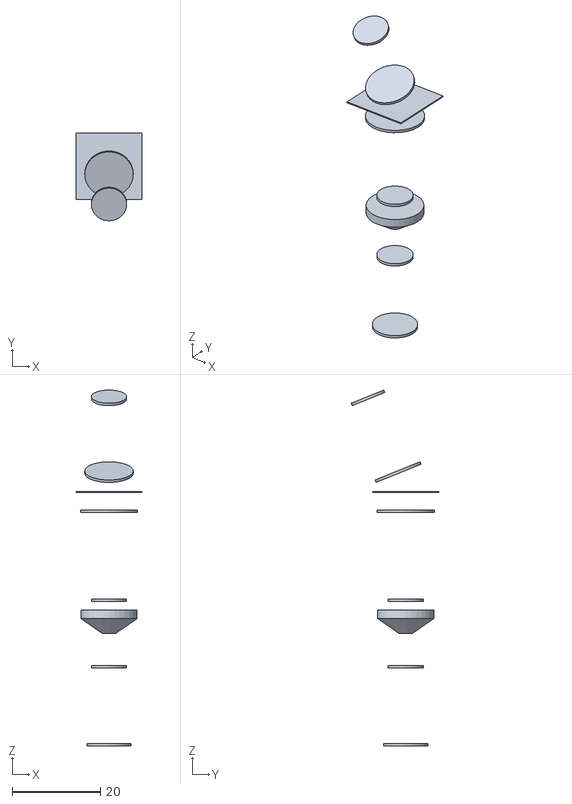
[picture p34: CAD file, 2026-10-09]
ros2/so101_scan_description/meshes/scan_head/head_glass.stl
15.0 x 19.9 x 80.7

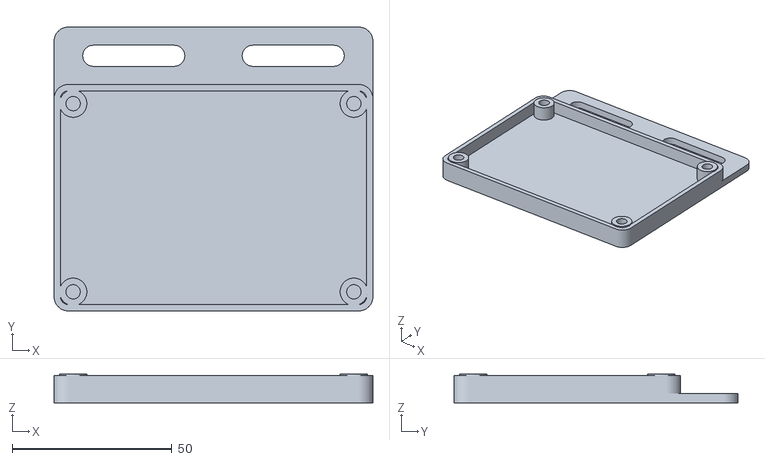
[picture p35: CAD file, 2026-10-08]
cad/stl/controller_tray.stl
100.0 x 89.0 x 9.00

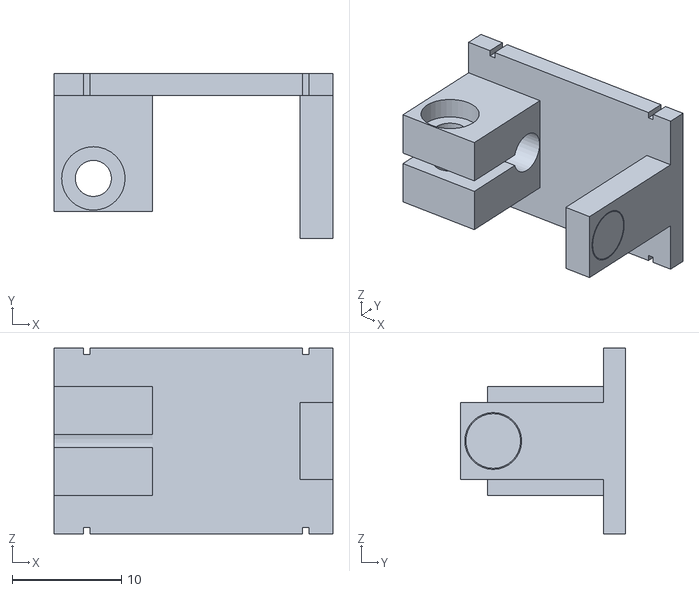
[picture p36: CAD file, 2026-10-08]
ros2/so101_scan_description/meshes/scan_head/mirror_clamp.stl
25.5 x 15.1 x 17.0

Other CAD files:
cad/stl/mirror_clamp.stl
ros2/so101_scan_description/meshes/scan_head/mirror_glass.stl
cad/stl/objective_carrier.stl
cad/stl/grating_carrier.stl
cad/stl/bench_puck.stl
cad/stl/stop_washer.stl
cad/stl/stop_washer_5mm.stl
cad/stl/wrist_puck.stl

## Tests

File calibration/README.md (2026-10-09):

# Spectrometer calibration kit

`hsical` turns raw frames from the spectrograph into calibrated spectra. One session of lamp frames, about ten minutes with a CFL bulb, a neon outlet tester, a halogen lamp on PTFE and a red laser pointer, gives:

- the **wavelength of every pixel**, from about 100 lamp lines between 490 and 970 nm;
- the **warp** that straightens the curved lamp lines (smile) and evens out the slit's length across wavelengths (keystone);
- the **spectral response**, so a frame becomes radiance, or reflectance against a white reference;
- a **report** with pass/fail checks, plots, and what to do when a check fails.

The parts haven't arrived yet, so the kit is built and tested on synthetic frames rendered through the [Optiland model](../optics/spectrograph_model.py). `python -m hsical selftest` renders a session from a deliberately imperfect copy of the design, calibrates it, and compares the result with the answer the frames were built from.

The other calibration here, [`headcal`](headcal/README.md), measures where the scanner head's cameras and mirror really sit on the wrist, from one scan of a printed tag board, and writes them into the URDF and the trainer's head model.

<p align="center">
  A synthetic CFL frame after calibration: wavelength from 484 to 970 nm across, slit rows down; every lamp line is a straight vertical stripe.
  <br><sub>A synthetic CFL frame after calibration. On the sensor these lines bow by up to 35 px; here each one is a straight column at its own wavelength.</sub>
</p>

## Contents

- [What you need](#what-you-need)
- [Install](#install)
- [First light, step by step](#first-light-step-by-step)
- [Reading the report](#reading-the-report)
- [Using a calibration](#using-a-calibration)
- [Checking for drift](#checking-for-drift)
- [How it works](#how-it-works)
- [Testing without the hardware](#testing-without-the-hardware)
- [Limits](#limits)
- [Code map](#code-map)

## What you need

| Item | What it calibrates | Notes |
|---|---|---|
| CFL bulb, any compact fluorescent | wavelength: mercury, argon and phosphor lines from 490 to 970 nm | Let it warm up for 2 to 3 minutes first. |
| Neon glow lamp: the Sperry GFI6302N outlet tester, or a bare NE-2 | wavelength: dozens of neon lines from 533 to 967 nm | It must glow orange; an LED tester won't work. |
| Halogen lamp (the HDX work light) and a PTFE sheet | slit ends, keystone, spectral response | A filament is close to a blackbody, so its spectrum is known. |
| 3 to 5 thin wires, 0.1 to 0.3 mm | keystone along the slit | Guitar string, magnet wire or a hair. |
| Red diode laser | a check that the smile correction worked | Not a wavelength reference: a diode's wavelength drifts a few nm with temperature. |
| Lens cap or black cloth | darks | |

**Safety.** The outlet tester runs on mains voltage: hold it by its plastic body, never open it, and plug it in only while capturing. Never point the laser into the optics or anyone's eyes; aim it at the PTFE so the slit sees the diffuse spot. Halogen bulbs get hot enough to burn and to scorch the PTFE, so keep a few centimetres between them. A CFL holds a little mercury; if one breaks, air the room out before cleaning up.

## Install

**PC** (Windows, Linux or macOS, Python 3.10 or newer), from this folder:

```bash
pip install -r requirements.txt
python -m hsical selftest        # renders, calibrates and checks a small synthetic session: under a minute
```

**Jetson Nano** (JetPack 4: its stock Python 3.6 and numpy are enough). Copy this folder over, or clone the repo, then:

```bash
sudo apt install v4l-utils python3-numpy
cd calibration
python3 -m hsical probe          # lists the camera's formats and controls
```

Look for the `RG10` format at 3264 x 2464 and the `exposure`, `gain` and `frame_rate` controls. If your driver names them differently, pass the names with `--ctrl`, for example `--ctrl exposure_ctrl=exposure_time_absolute`. Every capture command accepts `--dry-run`, which prints the `v4l2-ctl` command line instead of running it. A Raspberry Pi works too: the kit uses picamera2's raw stream there.

Raw frames matter. The normal camera pipeline (`nvarguscamerasrc`, libcamera's processed output) demosaics, white-balances and applies a tone curve, and all of that bends the numbers. The capture commands read the sensor's own 10-bit values.

## First light, step by step

### 1. Look at a lamp frame

With the CFL lit in front of the slit, the frame should show bright vertical lines. The spectrum runs along the sensor's long side, blue on the left, and the slit runs top to bottom between rows 123 and 2340. A camera mounted on its side or flipped is fine: the kit finds out from the frames and turns them.

Where the design puts the brightest lines, in the middle of the slit, counting columns across the full 3280-px width (the Jetson's 3264-px mode trims a few):

| Line | nm | Column | Lamp |
|---|---|---|---|
| Mercury, green | 546.1 | 480 | CFL, the brightest line |
| Neon | 585.2 | 700 | neon |
| Europium phosphor, red | 611.4 | 848 | CFL, second brightest |
| Neon | 640.2 | 1011 | neon, one of the brightest |
| Red laser | about 650 | about 1067 | laser |
| Neon | 703.2 | 1371 | neon |
| Argon | 763.5 | 1718 | CFL, long exposure |
| Argon | 811.5 | 1998 | CFL, long exposure |
| Argon | 912.3 | 2599 | CFL, long exposure |
| Neon | 966.5 | 2931 | neon, long exposure |

A real build will sit a hundred pixels or so away from these columns, which is fine. What should match is the pattern: the two brightest CFL lines are about 370 px apart. The design spreads 5.6 px per nm at 500 nm and 6.3 px per nm at 1000 nm, and a line is about 24 px wide, which works out to 4 nm of spectral resolution.

### 2. Focus

```bash
python3 -m hsical focus --exposure-ms 20
```

With the CFL lit, this prints the width of the brightest line, frame after frame. Turn the camera lens slowly and stop at the smallest number. The slit's own image is 23 to 24 px wide, so the width can't go below that. Perfect lenses would get within a pixel or two of it; real M12 lenses will probably bottom out somewhere around 30 to 45 px, which is 5 to 8 nm of resolution. What matters is finding the minimum. Keep the peak level the command prints between 40% and 90% by changing `--exposure-ms`. The camera lens can only fix its own focus: the collimator has to sit one focal length (25 mm) from the slit, as the printed housing holds it. If the minimum is broad and high, check that spacing first.

### 3. Capture a session

```bash
python3 -m hsical plan ~/sessions/first_light
```

This walks through each setup in turn, waits for Enter, sets the exposure on its own, and shows the peak level and saturation after every set; `r` retakes a set. At the end it takes darks at every exposure and gain it used.

| Set | Setup | Exposure | What it gives |
|---|---|---|---|
| `flat` | Halogen on the PTFE, the sheet filling the slit's view | 75% of full scale | Slit ends, keystone, spectral response, the colour mosaic's pattern |
| `wires` | Same light, with 3 to 5 wires across the PTFE, spread along the slit | Same as the flat | Dark notches at fixed points along the slit, for the keystone |
| `cfl` | CFL in front of the slit, room lights off | 75% | Mercury and phosphor lines |
| `cfl_long` | Same | 10x longer | The faint argon lines from 700 to 970 nm; the bright lines saturate on purpose |
| `neon` | Neon lamp right at the slit | 75% | Neon lines from 533 to 750 nm |
| `neon_long` | Same | 10x more light (gain goes up past 650 ms) | Neon lines from 750 to 967 nm |
| `laser` | Red laser spot or line on the PTFE | 60% | A check of the smile correction |
| `dark_*` | Lens capped or slit covered, lamps off | Each exposure and gain used above | Black level and hot pixels |

On the bench, before the objective is fitted, hold a piece of PTFE against the slit with the halogen shining through it, and lay the wires straight across the slit. Once the objective is in, the PTFE and wires go where the scan line falls, in focus. Each set is 16 frames (8 for the laser); at full resolution a whole session comes to about 3 GB, and `--frames 8` halves that. `--steps flat,wires` retakes only those sets.

### 4. Copy the session to the PC and check it

```bash
scp -r <user>@<jetson-address>:sessions/first_light .
python -m hsical inspect first_light
```

`inspect` lists each set with its exposure, gain, peak level, saturation and matching dark. It flags anything that would stop a calibration (no lamp set, a saturated flat, sets of different frame sizes) and notes anything that would weaken one (a missing dark or long set, an exposure that's too faint).

### 5. Calibrate

```bash
python -m hsical calibrate first_light -o cal
```

At full resolution this takes one to two minutes and 2.5 GB of memory. It writes `cal/report.md` with its plots, `cal/calibration.json` and `cal/maps.npz`, and exits with code 2 if a check fails. Options worth knowing: `--temp-k` sets the halogen's filament temperature (2850 K by default), `--nm-step` sets the wavelength step of the output (2 nm by default), and `--lamps cfl,neon` leaves out sets you don't trust.

If the line pattern ever matches the wrong way, so that the lamp plot's ticks sit beside the peaks instead of on them, tell the kit where one line is. Add a `session.json` to the session folder with the column of the bright green mercury line, counted with blue on the left: `{"hints": {"cfl": [[546.07, 572]]}}`.

## Reading the report

`report.md` opens with a table of checks:

| Check | Passes when | If it fails |
|---|---|---|
| flat exposure | Under 0.01% of the flat's pixels saturated | Retake the flat shorter: `plan --steps flat,wires`. |
| wavelength fit | Under 0.3 nm rms, with 8 or more lines | Refocus, check the lamp exposures, and look in the line table for lines with large residuals. |
| lines cover the band | Lines from below 560 nm to above 850 nm | Retake the long neon and CFL sets. |
| smile fit | Residuals under 0.3 line widths, with 6 or more lines followed | The lines are too faint near the slit's ends: light the whole slit evenly, or expose longer. |
| keystone fit | Under 0.5 px | The flat is uneven; look at the slit ends in the keystone plot. |
| slit evenness | No dips over 3%, under 15% brighter at one end than the other | A note, never a failure. Dips are usually dust on the slit; blow it clean. The response map corrects whatever remains. |
| laser straight along the slit | Under 0.15 nm rms | The smile correction is off; look at the traces in the smile plot. |

Under the checks come the numbers worth tracking from one build or session to the next: wavelength range, dispersion in px per nm, line width and resolution in nm, how far the lines bow at the slit's ends, where the slit ends are, the usable band, and the laser's measured wavelength. Then come the plots:

<p align="center">
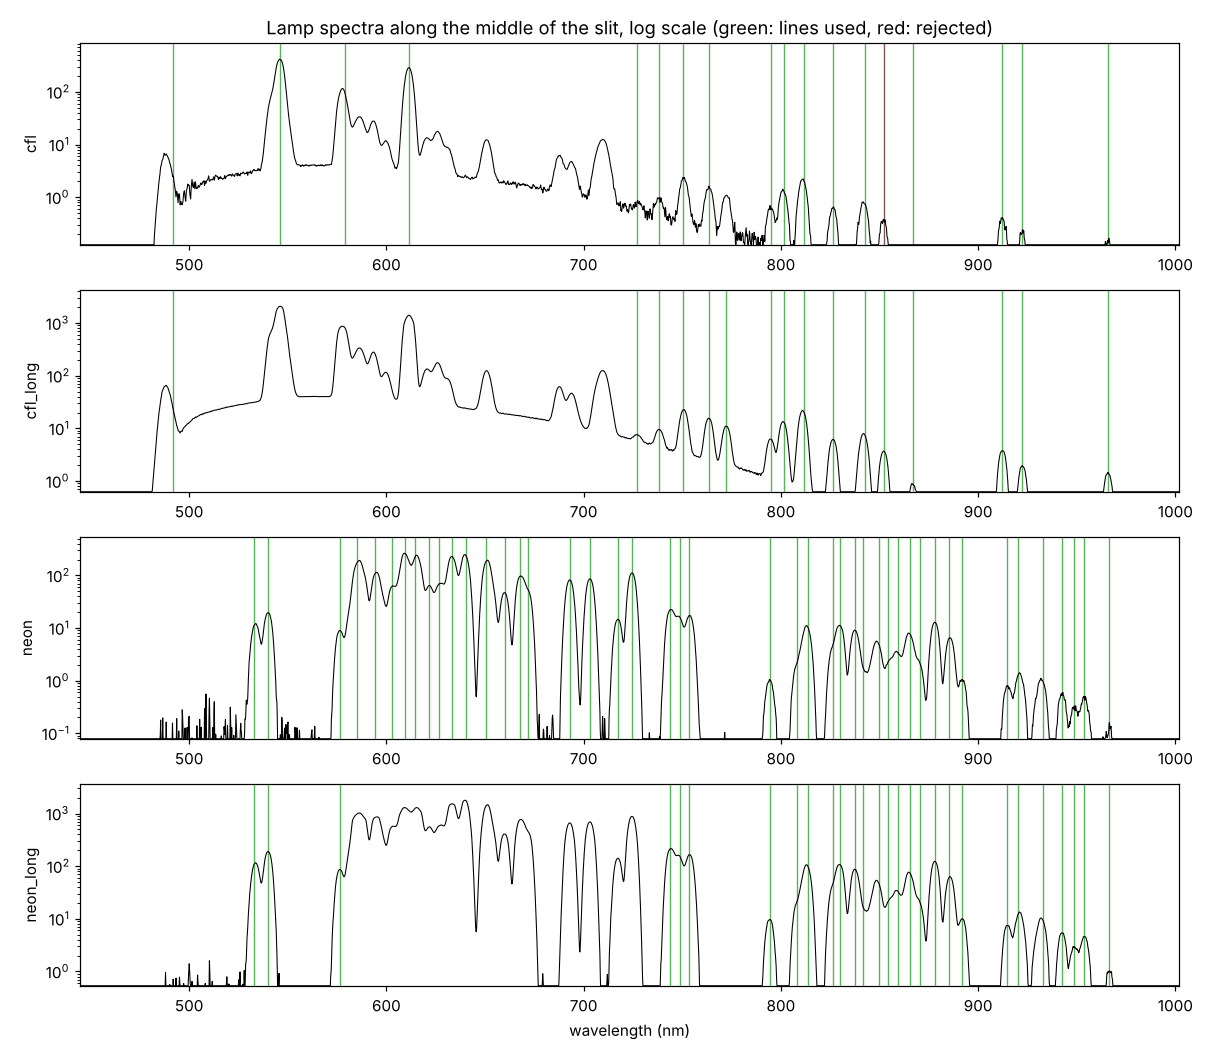
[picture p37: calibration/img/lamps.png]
Four panels of lamp spectra on a log scale along the middle of the slit: CFL, long CFL, neon and long neon, from 450 to 1000 nm, with a thin vertical line at every catalog line the fit used. The long sets bring up the faint lines past 750 nm.
  
  <br><sub>Synthetic lamp spectra along the middle of the slit, on a log scale. Each green tick is a catalog line the wavelength fit used, and red ones were rejected. The long sets saturate the bright lines and bring up the faint ones past 750 nm.</sub>
</p>

At the end of the report, the lamp-line table lists every line the fit tried: its catalog wavelength, measured column and uncertainty, signal-to-noise, how many neighbouring lines were fitted with it, and how far it lands from the final curve. The log of the run comes last.

## Using a calibration

**From the command line.** Capture frames of something, a white PTFE reference under the same light, and a dark, then turn them into spectra:

```bash
# on the Jetson
python3 -m hsical capture scans leaf --kind scene --exposure-ms 30
python3 -m hsical capture scans white --kind white --source ptfe --exposure-ms 30
python3 -m hsical capture scans dark_30ms --kind dark --exposure-ms 30
# on the PC
python -m hsical apply cal scans/leaf --dark scans/dark_30ms                       # radiance
python -m hsical apply cal scans/leaf --dark scans/dark_30ms --white scans/white   # reflectance
```

Each writes `spectra/leaf_radiance.npy` (or `_reflectance`), a float32 array of frames x slit rows x wavelengths, along with a `.json` file holding the wavelength and slit axes and a `.png` preview. `--dark 64` subtracts the sensor's black level when no dark was taken.

**From Python:**

```python
from hsical.model import Calibration

cal = Calibration.load("cal")
line = cal.radiance(raw, dark, exposure_us=30000)      # (slit rows, wavelengths)
refl = cal.reflectance(raw, dark, 30000, white, white_dark, 30000)
cal.nm_grid, cal.s_grid                                 # the axes of both
cal.wavelength_at(x, y)                                 # nm at any pixel
```

**From C++ or CUDA.** `maps.npz` is a plain numpy archive; [cnpy](https://github.com/rogersce/cnpy) reads it, or re-save the arrays as raw float32. It holds:

| Array | Shape | Meaning |
|---|---|---|
| `map_x`, `map_y` | slit rows x wavelengths | The sensor pixel to sample, bilinearly, for each output cell: the same convention as OpenCV's `remap`, so the warp is one gather kernel. |
| `nm_grid`, `s_grid` | 1-D | Wavelength (nm) of each output column and slit row of each output row. |
| `wavelength`, `slit` | sensor rows x columns | Wavelength and slit position of every raw pixel, for a renderer that models raw pixels instead of resampled cells. |
| `response` | sensor rows x columns | Counts per second, at gain 1, per unit of relative radiance. |
| `bad` | sensor rows x columns | Hot and dead pixels to skip. |

All of these are in the turned frame: spectrum along x, blue on the left. If `sensor.orientation` in `calibration.json` isn't all `false`, turn each raw frame the same way first: transpose, then mirror x, then mirror y. One output cell spans several pixels (a 2 nm step is about 12 columns), so average over a cell before sampling: a box as wide as the step along x, and a [1 2 1] filter along the slit, as `Calibration.rectify` does. For radiance, warp the dark-subtracted counts per second and the response map that way separately, then divide one by the other. Dividing first lets the colour mosaic's dim pixels through as noise.

## Checking for drift

A printed housing shifts a little with temperature and handling, and a knock can move the slit or the camera. Before a scanning session, take one CFL set (or neon) and a dark in the sensor mode the calibration was made in, and check it against the calibration:

```bash
# on the Jetson
python3 -m hsical capture checks cfl --kind lamp --source cfl --exposure-ms 60 --frames 4
python3 -m hsical capture checks dark_60ms --kind dark --exposure-ms 60 --frames 4
# on the PC
python -m hsical check cal checks/cfl
```

`check` fits every lamp line the calibration used, in five bands along the slit and the way `calibrate` fitted it, and compares where each one is with where the calibration puts it. It also finds the slit's two ends along the brightest lines. On a synthetic session, a fresh CFL set of the calibrated instrument reads:

```
  wavelength offset    +0.036 nm (+0.04 px; + means the lines moved toward red)
  along the slit       -0.047 nm end to end (camera or slit turned)
  across the spectrum  +0.021 nm blue to red (grating or camera lens moved)
  worst anywhere       +0.070 nm, limit 0.2   ok
  lines about the fit  0.042 nm rms (weighted), 0 outlier(s) left out
  slit ends            -0.21 / +0.15 rows (top / bottom), -0.005% of the slit, limit 0.2%   ok
Still calibrated: the lines are where the calibration puts them.
```

The offset, the tilt along the slit and the stretch across the spectrum make a plane through every line's shift; "worst anywhere" is that plane's largest value over the sensor, against a limit of 0.2 nm. The slit ends catch a move along the slit, which the lines alone can't see. With the same instrument knocked by 1.5 px along the spectrum and 2 rows along the slit, it reads an offset of 1.54 px and slit ends of +1.8 and +2.2 rows, and says to recalibrate.

It exits with 0 when the instrument is still calibrated and 2 when it has moved, so a scan script can stop first. `--dark` names the dark (it finds a matching one beside the frames otherwise, or subtracts the black level of 64), `--source` names the lamp for a frame file without a `meta.json`, `--max-nm` and `--max-slit-percent` change the limits, and `--json` saves every line's shift.

## How it works

**Sensor.** Each set is averaged over its frames, and the dark at the same exposure and gain is subtracted. Without an exact match, the kit interpolates between darks at nearby exposures, and with no darks at all it subtracts the black level of 64 counts. Hot pixels are found in the longest dark, odd ones in the flat, and both get filled in from same-coloured neighbours. The NoIR IMX219 has no infrared-cut filter but still has its red, green and blue dyes. Below about 800 nm, neighbouring pixels see up to ten times different amounts of the same light; past 800 nm the dyes go clear and the mosaic fades out. The kit measures that pattern from the flat and evens it out before looking for lines.

**Wavelength.** Lamps emit at fixed wavelengths, listed in the [NIST Atomic Spectra Database](https://physics.nist.gov/asd): mercury and argon in a CFL, neon in a glow lamp, plus the peaks of the CFL's europium and terbium phosphors. The kit first slides and stretches the spectrum predicted from the design along the measured one until the line patterns match, so it knows which bump is which line even if the camera sits well off its designed position. At this resolution, lines closer than about 5 nm merge into one bump. Where that bump peaks depends on how bright each line is, and no catalog knows that for your particular lamp. So each bump is fitted as its known set of lines, with their spacings fixed and their brightnesses free. Phosphor bands, which are broad and only roughly catalogued, get free positions too. Those fits need the right line shape: the slit's flat-topped image, softened by the lens blur. A line on its own can't tell a wide slit image with little blur from a narrow one with a lot, but overlapping lines can, so the kit tries a range of widths and splits on the strongest groups and keeps the one they fit best. In the synthetic tests with a soft lens, the wrong shape moved some lines by more than a nanometre. The column-to-wavelength curve is the design's curve plus a gentle cubic correction, fitted to every line weighted by its uncertainty, and lines that miss by more than 4 sigma are dropped. The near-infrared lines are tens to hundreds of times fainter than the bright visible ones, and the sensor loses sensitivity past 800 nm, so the long sets let the bright lines saturate to bring the faint ones up; saturated columns are skipped.

**Smile.** Light from the ends of the slit reaches the grating slightly out of the plane it disperses in, and diffracts a little further (conical diffraction). So each lamp line is a gentle arc, with its ends 15 to 32 px further toward the red than its middle. The kit follows dozens of lines from the middle of the slit to its ends and fits a smooth surface that gives each pixel's offset.

**Keystone.** The slit's image is not the same length at every wavelength, because the camera lens magnifies a little differently across the band; in the design it is about 20 px longer at the ends of the band than in the middle. The ends of the slit in the flat, and the wires' shadows, mark fixed points along the slit at every wavelength. A second smooth surface maps each pixel to its position along the slit.

**Rectification.** Together, the two surfaces say which wavelength and which slit point every pixel sees. Inverting that once gives a lookup table, `map_x` and `map_y`, that resamples a frame onto a regular grid: one row per slit point and one column per wavelength step, with every lamp line straight. On the Jetson this is a single gather kernel per frame.

**Spectral response.** A halogen filament glows close to a blackbody at about 2850 K, so Planck's law gives its spectrum. Dividing the flat by that spectrum gives the response: counts per second, per pixel, per unit of light at that pixel's wavelength. It folds in the filter, the grating's efficiency, the lenses, the sensor's sensitivity and the colour dyes. Radiance is then counts divided by response, in units of that blackbody normalised to 1 at 700 nm. Reflectance, the scene's counts divided by a white PTFE reference's under the same lamp, needs no response and no filament temperature at all. Reflectance is what the splat trains on.

## Testing without the hardware

[`tools/export_optiland_map.py`](tools/export_optiland_map.py) traces the Optiland model with ideal thin lenses, at the spacings the CAD model actually builds and with the focal lengths and stop of the lenses that were bought, and records where each point of the slit lands on the sensor at each wavelength. The result, [`hsical/data/optiland_map.json`](hsical/data/optiland_map.json), is used two ways: as the starting guess for which column sees which wavelength, and to render synthetic sessions.

```bash
python -m hsical synth synth_session --binning 2     # 1 = full 3280 x 2464, 2 = half, 4 = quarter
python -m hsical calibrate synth_session -o synth_cal
```

The synthetic instrument is deliberately not the design. Its spectrum is shifted and rotated on the sensor, its grating is 1.2% denser, and its lens has some barrel distortion and blur. Its lamps' line brightnesses scatter around the catalog's, its slit has dust and a tapered width, and its sensor has the IMX219's colour mosaic, a guessed NoIR response, shot and read noise, and hot pixels. The calibration has to measure all of that. A full-resolution self-test (`selftest --binning 1`, about five minutes, most of it rendering):

| Error against the truth | Result | Limit |
|---|---|---|
| Wavelength of every pixel, rms | 0.020 nm | 0.10 nm |
| Wavelength of every pixel, worst | 0.070 nm | 0.30 nm |
| Wavelength of every rectified cell, worst | 0.076 nm | 0.30 nm |
| Slit position across a rectified row, worst spread | 0.012 px | 0.30 px |
| Laser wavelength | 0.003 nm | 0.20 nm |
| Reflectance of a test scene, rms | 0.8% | 3% |

The largest wavelength errors sit beyond the outermost lamp lines, where the curve is extrapolated.

A real M12 lens will likely be softer than this synthetic one, so the tests also run a session with twice the blur, where lines come out about 6 nm wide; it stays within the same limits. `pytest` runs 24 tests of `hsical` in about a minute and a half (and [`headcal`](headcal/README.md#testing-without-the-hardware)'s 22 in about 20 seconds more): the whole chain on quarter-size sessions (as designed, with the soft lens, and with the camera turned sideways and mirrored), the drift check on fresh lamp frames of the calibrated instrument as it was and knocked, plus the building blocks. They need numpy 2 and scipy 1.15 or newer, which is what pip installs on Python 3.10 and up: with older versions the wavelength fit finds fewer near-infrared lines or fits them less closely, and a few tests miss their limits.
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

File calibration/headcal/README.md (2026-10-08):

# Head calibration (headcal)

The URDF puts the scanner head's parts where the CAD model draws them. The printed head won't match that exactly: a part seated half a millimetre off, a mirror shaft a degree out of square, a horn screwed on a little turned. At the 15 cm scan distance one degree of error moves the scan line 2.6 mm, about nine scan lines, and the splat trainer needs every line placed to a fraction of one. `headcal` measures where the parts really are, from one calibration scan of a printed tag board, and writes the result back into the URDF and the trainer's head model.

<p align="center">
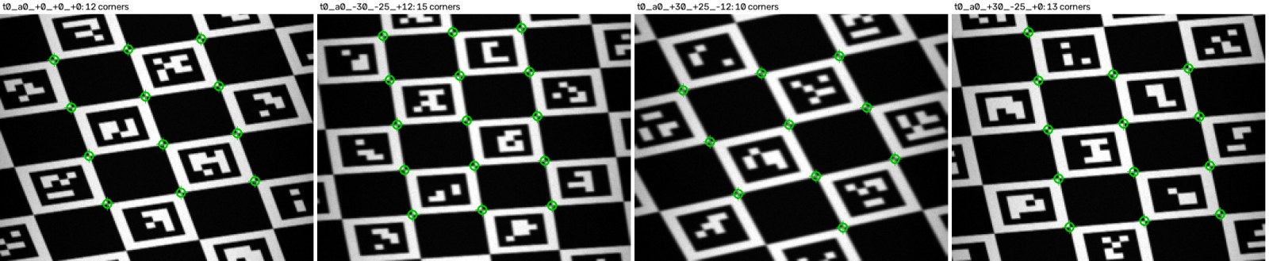
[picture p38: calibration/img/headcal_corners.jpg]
Four sweeps of the tag board as the line camera saw them in a synthetic calibration scan: a chequerboard with square tags, slanted and stretched by the sweep, with the board corners the solver found circled in green.
  
  <br><sub>Four sweeps of the tag board as the line camera builds them up, line by line, in a synthetic calibration scan, with the corners the solver matched circled.</sub>
</p>

It measures:

| What | URDF joint | Why it matters |
|---|---|---|
| The head on the wrist servo horn | `scan_head_mount` | Every pose the arm reports goes through it. |
| The mirror shaft's position and direction, and its home angle | `scan_mirror_joint` | Where the view points at each mirror step. The home angle is where the hall sensor really puts the mirror's zero. |
| The objective (the slit's line of sight) | `spectrograph_optical_joint`, and the folded `line_camera_optical_joint` that follows from it | Where each pixel of the slit looks. |
| The scan line's length | the `scan_line_frame` box | The line camera's focal length. |
| The pose camera, and its lens | `pose_camera_joint`, `pose_camera.yaml` | For tag-board poses later, and as the bridge to the line camera here. |

It doesn't touch the arm's own joint zeros (`sts_calibrate` sets those) or the spectrograph's wavelengths (that's [`hsical`](../README.md)).

## Contents

- [What you need](#what-you-need)
- [First light, step by step](#first-light-step-by-step)
- [Reading the report](#reading-the-report)
- [Using the result](#using-the-result)
- [How it works](#how-it-works)
- [Testing without the hardware](#testing-without-the-hardware)
- [Limits](#limits)
- [Code map](#code-map)

## What you need

- The rig working end to end: the arm calibrated with `sts_calibrate`, the mirror homing, and `line_camera` binning lines with an `hsical` calibration ([`ros2/README.md`](../../ros2/README.md#scanning-with-the-spectrograph-camera)).
- The pose camera (the Pi Camera Module v2 NoIR on the head) on the Nano's second camera port, `/dev/video1`.
- A **laser printer**. Toner is carbon black and stays black in the near infrared; most inkjet inks go transparent past about 700 nm, and the board would fade out of half the bands.
- Stiff, flat card or foam board to glue the print to, and calipers or a steel rule.
- The halogen lamp, lighting the board evenly.
- On the PC, this folder's requirements: `pip install -r requirements.txt` (they include OpenCV and xacro).

## First light, step by step

**1. Print the board.** On the PC, from `calibration/`:

```bash
python -m headcal board ~/headcal
```

This writes `board.svg`: a ChArUco board (a chequerboard with a small square tag in every white square, 24 x 17 squares of 10 mm) on letter paper, with a 100 mm check bar. Print it at 100% ("actual size", not "fit to page") and measure the bar; if it isn't 100.0 mm, the printer scaled it. Glue the print flat onto the card. Then measure 20 squares along the long side as closely as you can and tell `headcal` what you got, for example:

```bash
python -m headcal board ~/headcal --span-mm 199.6
```

That rewrites `board.json` to the printed size (it leaves `board.svg` alone). The board's size sets the scale of everything the calibration measures, so a 0.5% printer error would otherwise become a 0.5% error in every distance.

**2. Place the board.** Lay it flat on the table with its centre 260 mm in front of the arm's base, on base_link's x axis (the centre ticks on its edges help; Foxglove's TF view shows the axis). A centimetre or two off and turned up to about 20° is fine: the calibration measures where the board is. For another spot, make a new plan: `python -m headcal plan --centre 0.24 0.03 --out myplan.yaml`.

**3. Bring up the rig.** In the ROS container (`ros2/docker/run.sh`), start the arm, the mirror and the spectrograph camera as for any scan, with the head at its CAD numbers:

```bash
ros2 launch so101_scan_bringup scan_arm.launch.py camera:=v4l2 camera_calibration:=/data/hsical/cal head_calibration:=none
```

Home the mirror (`ros2 service call /scan_mirror/home std_srvs/srv/Trigger`), then in a second container shell move the arm to the plan's first viewpoint, straight above the board:

```bash
ros2 run so101_scan_sweep move_arm --plan src/linescan-hyperspectral-splatting/calibration/headcal/plans/headcal.yaml
```

Light the board evenly with the halogen lamp and set the line camera's exposure so the board's white paper reads 50 to 90% of full scale, as for a white reference.

**4. Focus the pose camera.** The Camera Module v2's lens is set for far away. On the Nano host (not in the container), from `calibration/`:

```bash
python3 -m headcal record /tmp/focus --device /dev/video1 --focus
```

It prints a sharpness number every second or so. Turn the lens with the focus tool until the number peaks, then Ctrl+C.

**5. Start the recorder**, also on the host, from `calibration/`:

```bash
python3 -m headcal record ~/so101_scan/pose/headcal_1 --device /dev/video1 --auto 0.7
```

`--auto 0.7` first sets the exposure so the brightest part of the view reads about 70% of full scale. Then it grabs a frame every second and keeps one as soon as the view stops changing, and another every 3 seconds while it holds, so each viewpoint gets a few stills taken while the arm holds still for its sweep. Leave it running.

**6. Run the calibration scan**, in the second container shell. With `--dry-run` first, it plays the plan in Foxglove without moving anything and reports any viewpoint that comes too close to the table or a sweep the mirror can't make; then the same without `--dry-run` scans:

```bash
ros2 run so101_scan_sweep scan_sweep --plan src/linescan-hyperspectral-splatting/calibration/headcal/plans/headcal.yaml --dry-run
ros2 run so101_scan_sweep scan_sweep --plan src/linescan-hyperspectral-splatting/calibration/headcal/plans/headcal.yaml
```

The plan visits 22 viewpoints, from straight down to 35° tilted and from several sides, with the board up to 12 mm nearer and farther than the scan line's focus, and sweeps 213 lines at each (one microstep a line). When the scan finishes, stop the recorder with Ctrl+C; it says how many stills it kept (two to four per viewpoint; the solver uses those taken during a sweep and leaves out the rest).

**7. Solve on the PC.** Copy the scan folder and the stills over, then from `calibration/`:

```bash
scp -r nano:so101_scan/scans/headcal_<time> nano:so101_scan/pose/headcal_1 .
python -m headcal solve headcal_<time> headcal_1 --board ~/headcal/board.json -o headcal_out
```

It takes under a minute and writes `headcal_out/report.md`, which is the next thing to read.

**8. Install it.** Copy `headcal_out/head_calibration.yaml` to the Nano as `~/so101_scan/head_calibration.yaml`. From then on `scan_arm.launch.py` builds the URDF with it (its log says `scanner head: calibrated, from ...`), so TF, Foxglove, `lines.csv` and every new scan use the measured head. `head_calibration:=none` goes back to the CAD numbers for one launch.

## Reading the report

**Fit.** Three numbers say whether the solve held together:

- *Pose camera*: corners found in its stills and how far they sit from where the fitted lens puts them. Under 0.3 px rms is good.
- *Line camera*: board corners matched in the sweeps, and how far they sit from where the fitted head puts them, along the slit (pixels) and across it (lines). Under 0.3 is good. Fewer than about 8 corners per sweep usually means the board is too dim, out of focus, or not under the scan line.
- *Arm*: from each viewpoint, how far the board lands from where the other viewpoints put it. This is the arm's own repeatability and joint calibration, not the head's: half a millimetre is about what the STS3215's 0.09° steps give.

**Check these** lists anything that needs a look: a viewpoint that doesn't fit the others (the arm slipped, or a servo misread), the pose camera mounted another way round than the CAD has it, or the slit's pixel order reversed (the solver uses the order that fits and tells you to set `slit_reversed` in `line_camera`'s settings).

**What changed** gives each part's shift and turn from the CAD. A millimetre or two and a degree or three are normal for a printed head; ten millimetres or degrees mean a part is loose or seated wrong. The **mirror home angle** is the angle between where the firmware's homing parks the mirror and where its zero really is. The URDF carries it, so leave the firmware's `home_pos` alone.

**Per viewpoint** has every viewpoint's corner counts and residuals, to find the one that spoils a fit. `line_corners.png` shows the matched corners on the first sweeps.

## Using the result

- `head_calibration.yaml`: the xacro argument `head_calibration` (the launch file passes `~/so101_scan/head_calibration.yaml` when it exists).
- `robot.urdf`: the scan's URDF with the measured head, for anything that reads a URDF file. Scans taken before the calibration convert with it: `python3 splat/tools/scan_to_dataset.py <scan> <dataset> --urdf headcal_out/robot.urdf` works out each line's pose again from the joint readings in `lines.csv`, and takes the trainer's head model and focal length from the calibrated URDF.
- `pose_camera.yaml`: the pose camera's lens as a ROS `camera_info` file (at the stills' 1632 x 1232).
- `calibration.json`: everything above with uncertainties, the trainer's head model, and the board's pose on the table.

Calibrate again after taking the head off the wrist, re-running `sts_calibrate`, changing the mirror's `home_pos`, or knocking a camera. It's one scan.

## How it works

**Two cameras on one head.** The pose camera is an ordinary camera. The line camera is a pushbroom camera: the objective and slit see one line of the scene, the mirror sweeps that line across the board, and stacking the lines builds up a picture whose rows are mirror steps (the sweeps above). Optically, the line camera is the objective seen in the mirror, a virtual camera that turns twice as fast as the mirror; the URDF already models it that way.

**Step 0: the pose camera.** The board's tags give every corner an identity, so OpenCV finds hundreds of numbered corners in each still. From 22 views of a flat board of known size, `calibrateCamera` fits the lens (focal length, centre, distortion), and `solvePnP` gives the board's pose in the camera for each view.

**Hand-eye.** The board doesn't move, but the arm does. For any two viewpoints, how the wrist moved (from the joint readings) and how the board seemed to move in the camera must be the same motion seen from two places, which is the classic hand-eye equation AX = XB. Its rotation part is a fitting problem over the turn axes of all pairs of viewpoints (Park and Martin's method); the translation follows by least squares. That gives the pose camera on the wrist, and the board on the table.

**Step 1: the line camera.** With the board's pose known from the pose camera, the solver renders the sweep each viewpoint should have produced, from the current guess of the head, and matches it against the real sweep: first as a whole (all sweeps together, so the board's repeating squares can't make one sweep lock a square off), then corner by corner. Each matched corner says that at a known mirror step, a known pixel of the slit looked at a known point of the board. One least-squares fit then adjusts everything at once: the pose camera's lens, the objective's position and direction, the mirror shaft's position, direction and home angle, the scan line's length and a little distortion along the slit, and each viewpoint's board pose, which both cameras must agree on. Corners that don't fit are dropped and the rest matched again, three times. This step uses only the two cameras, so the arm's errors can't leak into where the line camera sits relative to the pose camera.

**Step 2: back on the wrist.** The head found in step 1 is then put on the wrist with the hand-eye equation again, this time using every board pose from the joint fit. `--joint-offsets shoulder_lift,elbow_flex,wrist_flex` also fits constant offsets of those joints, as a check of `sts_calibrate`'s zeros.

**What can't be told apart.** Some changes look the same in the data: turning the objective about the slit's line looks like moving the mirror's home angle, and sliding the slit's centre looks like turning the objective. The fit holds one of each pair at the CAD's number and lets the other take up the difference, which gives the same pixel-to-ray mapping, the only thing a scan depends on. The parts' frames are then lined up with the CAD's as closely as the measurements allow, so "what changed" reads as real shifts and turns.

## Testing without the hardware

`python -m headcal selftest` renders a whole calibration scan of a head that is off its CAD numbers by about what a printed head is (up to a millimetre and a couple of degrees per part, the mirror's home off by a degree or two), with a real lens's distortion on the pose camera, 0.03° of noise on every joint reading, and noise, vignetting, lamp fall-off and defocus in both cameras. It calibrates that scan and compares the result with the head it was rendered from. The line camera's accuracy is measured where it counts: pixels' rays against the true ones on the board, at three mirror angles and three points along the slit from every viewpoint.

| Error against the truth | Self-test | Limit |
|---|---|---|
| Line camera rays on the board, median | 0.17 mm | 0.40 mm |
| Line camera rays on the board, worst | 0.26 mm | 0.80 mm |
| Pose camera on the wrist | 0.13 mm, 0.03° | 0.50 mm, 0.15° |
| Pose camera focal length | 0.04 px | 0.5 px |
| Scan line length | 0.05% | 0.3% |

A scan line is about 0.3 mm on the board, so the calibration places it to about half a line. Harder synthetic cases, each a different random head:

| Case | Rays, median / worst |
|---|---|
| The head 2.5 times further off the CAD | 0.27 / 0.60 mm |
| The pose camera mounted upside down | 0.11 / 0.18 mm (and a warning) |
| Only 10 of the 22 viewpoints | 0.40 / 0.55 mm |
| `slit_reversed` wrong in `line_camera`'s settings | 0.15 / 0.23 mm (found, and a warning) |
| Arm joint zeros 1°, 0.8° and 0.6° off | 0.21 / 0.33 mm; with `--joint-offsets`, 0.14 / 0.23 mm and the offsets found within 0.06° |
| No noise on the joint readings | 0.001 / 0.003 mm |

The last row shows where the error comes from: almost all of it is the arm's joint readings, which put the head on the wrist. `pytest` (in `calibration/`) runs the pieces one at a time and an 8-viewpoint scan end to end, including the check that `head_calibration.yaml` builds through xacro into exactly the URDF the solver describes.

## Limits

- **The arm sets the floor.** The STS3215 reads 4096 steps a turn (0.09°), and gears have backlash, so a real arm will likely land the head 0.3 to 0.5 mm less exactly than the synthetic one. The report's arm column measures it. More viewpoints average it down.
- **The mirror is modelled as turning about an axis in its own plane.** A shaft that wobbles, or a mirror glued at a slant to its shaft, can't be represented in the URDF's mimic joint; the fit would spread that error over the other parts.
- **The trainer's line camera is a pinhole.** The slit distortion the solver measures (a pixel or two at the slit's ends) is in the report and `calibration.json`, but nothing downstream uses it yet.
- **The board has to be flat.** A print that lifts 0.5 mm off its card is a 0.5 mm error in that corner. Glue it all over.
- **The face offset** (the mirror's surface in front of its shaft) stays at the CAD's 7.1 mm: changing it looks almost exactly like moving the shaft, which the fit does measure.
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

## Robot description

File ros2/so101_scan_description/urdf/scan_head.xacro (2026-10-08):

<?xml version="1.0"?>
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
<robot xmlns:xacro="http://www.ros.org/wiki/xacro">
  <xacro:include filename="$(find so101_scan_description)/urdf/scan_head_params.xacro"/>

  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

  <xacro:macro name="scan_head_mesh" params="name material">
    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
  </xacro:macro>

  <xacro:arg name="head_calibration" default=""/>

  <xacro:macro name="scan_head" params="parent">
    <xacro:property name="head_calibration_file" value="$(arg head_calibration)"/>
    <xacro:if value="${head_calibration_file == ''}">
      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
      <xacro:property name="obj_dy" value="${objective_y - mirror_shaft_y}"/>
      <xacro:property name="obj_dz" value="${objective_z - mirror_shaft_z}"/>
      <xacro:property name="obj_dn" value="${obj_dy * cos(mirror_rest) + obj_dz * sin(mirror_rest)}"/>
      <xacro:property name="mount_xyz" value="0 0 ${head_mount_z}"/>
      <xacro:property name="mount_rpy" value="${pi} 0 0"/>
      <xacro:property name="mirror_xyz" value="0 ${mirror_shaft_y} ${mirror_shaft_z}"/>
      <xacro:property name="mirror_rpy" value="${mirror_rest} 0 0"/>
      <xacro:property name="face_offset" value="${mirror_face_offset}"/>
      <xacro:property name="objective_xyz" value="0 ${objective_y} ${objective_z}"/>
      <xacro:property name="objective_rpy" value="${pi} 0 0"/>
      <xacro:property name="fold_rpy" value="${-mirror_rest} 0 0"/>
      <xacro:property name="folded_xyz" value="0 ${obj_dy - 2 * obj_dn * cos(mirror_rest)} ${obj_dz - 2 * obj_dn * sin(mirror_rest)}"/>
      <xacro:property name="folded_rpy" value="${2 * mirror_rest + pi} 0 0"/>
      <xacro:property name="pose_camera_xyz" value="${pose_camera_x} ${pose_camera_y} ${pose_camera_z}"/>
      <xacro:property name="pose_camera_rpy" value="${pose_camera_roll} 0 0"/>
      <xacro:property name="line_half_length" value="${scan_line_half_length}"/>
    </xacro:if>
    <xacro:unless value="${head_calibration_file == ''}">
      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
      <xacro:property name="head_cal" value="${xacro.load_yaml(head_calibration_file)}"/>
      <xacro:property name="head_cal_joints" value="${head_cal['joints']}"/>
      <xacro:property name="mount_xyz" value="${head_cal_joints['scan_head_mount']['xyz']}"/>
      <xacro:property name="mount_rpy" value="${head_cal_joints['scan_head_mount']['rpy']}"/>
      <xacro:property name="mirror_xyz" value="${head_cal_joints['scan_mirror_joint']['xyz']}"/>
      <xacro:property name="mirror_rpy" value="${head_cal_joints['scan_mirror_joint']['rpy']}"/>
      <xacro:property name="face_offset" value="${head_cal['face_offset']}"/>
      <xacro:property name="objective_xyz" value="${head_cal_joints['spectrograph_optical_joint']['xyz']}"/>
      <xacro:property name="objective_rpy" value="${head_cal_joints['spectrograph_optical_joint']['rpy']}"/>
      <xacro:property name="fold_rpy" value="${head_cal_joints['line_camera_fold_joint']['rpy']}"/>
      <xacro:property name="folded_xyz" value="${head_cal_joints['line_camera_optical_joint']['xyz']}"/>
      <xacro:property name="folded_rpy" value="${head_cal_joints['line_camera_optical_joint']['rpy']}"/>
      <xacro:property name="pose_camera_xyz" value="${head_cal_joints['pose_camera_joint']['xyz']}"/>
      <xacro:property name="pose_camera_rpy" value="${head_cal_joints['pose_camera_joint']['rpy']}"/>
      <xacro:property name="line_half_length" value="${head_cal['scan_line_half_length']}"/>
    </xacro:unless>

    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
    <joint name="scan_head_mount" type="fixed">
      <parent link="${parent}"/>
      <child link="scan_head_link"/>
      <origin xyz="${mount_xyz}" rpy="${mount_rpy}"/>
    </joint>

    <link name="scan_head_link">
      <inertial>
        <origin xyz="${head_com_x} ${head_com_y} ${head_com_z}" rpy="0 0 0"/>
        <mass value="${head_mass}"/>
        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
      </inertial>
      <xacro:scan_head_mesh name="head_printed" material="scan_head_printed"/>
      <xacro:scan_head_mesh name="head_dark" material="scan_head_dark"/>
      <xacro:scan_head_mesh name="head_metal" material="scan_head_metal"/>
      <xacro:scan_head_mesh name="head_glass" material="scan_head_glass"/>
      <xacro:scan_head_mesh name="head_filter" material="scan_head_filter"/>
      <xacro:scan_head_mesh name="head_pcb" material="scan_head_pcb"/>
      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
    </link>

    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
    <joint name="scan_mirror_joint" type="revolute">
      <parent link="scan_head_link"/>
      <child link="scan_mirror_link"/>
      <origin xyz="${mirror_xyz}" rpy="${mirror_rpy}"/>
      <axis xyz="1 0 0"/>
      <limit lower="${-pi}" upper="${pi}" effort="0.014" velocity="20.0"/>
    </joint>

    <link name="scan_mirror_link">
      <xacro:scan_head_mesh name="mirror_clamp" material="scan_head_accent"/>
      <xacro:scan_head_mesh name="mirror_glass" material="scan_head_mirror"/>
    </link>

    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
    <joint name="scan_mirror_face_joint" type="fixed">
      <parent link="scan_mirror_link"/>
      <child link="scan_mirror_face"/>
      <origin xyz="0 ${face_offset} 0" rpy="${-pi/2} 0 0"/>
    </joint>
    <link name="scan_mirror_face"/>

    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
    <joint name="spectrograph_optical_joint" type="fixed">
      <parent link="scan_head_link"/>
      <child link="spectrograph_optical_frame"/>
      <origin xyz="${objective_xyz}" rpy="${objective_rpy}"/>
    </joint>
    <link name="spectrograph_optical_frame"/>

    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
    <joint name="line_camera_fold_joint" type="revolute">
      <parent link="scan_mirror_link"/>
      <child link="line_camera_fold_link"/>
      <origin xyz="0 ${2 * face_offset} 0" rpy="${fold_rpy}"/>
      <axis xyz="1 0 0"/>
      <limit lower="${-pi}" upper="${pi}" effort="0" velocity="20.0"/>
      <mimic joint="scan_mirror_joint" multiplier="1" offset="0"/>
    </joint>
    <link name="line_camera_fold_link"/>

    <joint name="line_camera_optical_joint" type="fixed">
      <parent link="line_camera_fold_link"/>
      <child link="line_camera_optical_frame"/>
      <origin xyz="${folded_xyz}" rpy="${folded_rpy}"/>
    </joint>
    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
    <link name="line_camera_optical_frame">
      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
    </link>

    <joint name="scan_line_joint" type="fixed">
      <parent link="line_camera_optical_frame"/>
      <child link="scan_line_frame"/>
      <origin xyz="0 0 ${scene_distance}" rpy="0 0 0"/>
    </joint>
    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
    <link name="scan_line_frame">
      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
    </link>

    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
    <joint name="pose_camera_joint" type="fixed">
      <parent link="scan_head_link"/>
      <child link="pose_camera_link"/>
      <origin xyz="${pose_camera_xyz}" rpy="${pose_camera_rpy}"/>
    </joint>
    <link name="pose_camera_link"/>

    <joint name="pose_camera_optical_joint" type="fixed">
      <parent link="pose_camera_link"/>
      <child link="pose_camera_optical_frame"/>
      <origin xyz="0 0 ${pose_camera_lens}" rpy="0 0 0"/>
    </joint>
    <link name="pose_camera_optical_frame"/>
  </xacro:macro>
</robot>

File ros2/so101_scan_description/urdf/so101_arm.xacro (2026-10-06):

<?xml version="1.0"?>
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
<robot xmlns:xacro="http://www.ros.org/wiki/xacro">
  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

  <xacro:macro name="so101_arm">
    <link name="base_link">
      <inertial>
        <origin xyz="0.0137179 -5.19711e-05 0.0334843" rpy="0 0 0"/>
        <mass value="0.147"/>
        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
      </inertial>
      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
    </link>
    <link name="shoulder_link">
      <inertial>
        <origin xyz="-0.0307604 -1.66727e-05 -0.0252713" rpy="0 0 0"/>
        <mass value="0.100006"/>
        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
      </inertial>
      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
    </link>
    <link name="upper_arm_link">
      <inertial>
        <origin xyz="-0.0898471 -0.00838224 0.0184089" rpy="0 0 0"/>
        <mass value="0.103"/>
        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
      </inertial>
      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
    </link>
    <link name="lower_arm_link">
      <inertial>
        <origin xyz="-0.0980701 0.00324376 0.0182831" rpy="0 0 0"/>
        <mass value="0.104"/>
        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
      </inertial>
      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
    </link>
    <link name="wrist_link">
      <inertial>
        <origin xyz="-0.000103312 -0.0386143 0.0281156" rpy="0 0 0"/>
        <mass value="0.079"/>
        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
      </inertial>
      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
    </link>
    <link name="wrist_roll_link">
      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
    </link>
    <joint name="shoulder_pan" type="revolute">
      <origin xyz="0.0388353 -8.97657e-09 0.0624" rpy="3.14159 4.18253e-17 -3.14159"/>
      <parent link="base_link"/>
      <child link="shoulder_link"/>
      <axis xyz="0 0 1"/>
      <limit effort="10" velocity="10" lower="-1.91986" upper="1.91986"/>
    </joint>
    <joint name="shoulder_lift" type="revolute">
      <origin xyz="-0.0303992 -0.0182778 -0.0542" rpy="-1.5708 -1.5708 0"/>
      <parent link="shoulder_link"/>
      <child link="upper_arm_link"/>
      <axis xyz="0 0 1"/>
      <limit effort="10" velocity="10" lower="-1.74533" upper="1.74533"/>
    </joint>
    <joint name="elbow_flex" type="revolute">
      <origin xyz="-0.11257 -0.028 1.73763e-16" rpy="-3.63608e-16 8.74301e-16 1.5708"/>
      <parent link="upper_arm_link"/>
      <child link="lower_arm_link"/>
      <axis xyz="0 0 1"/>
      <limit effort="10" velocity="10" lower="-1.69" upper="1.69"/>
    </joint>
    <joint name="wrist_flex" type="revolute">
      <origin xyz="-0.1349 0.0052 3.62355e-17" rpy="4.02456e-15 8.67362e-16 -1.5708"/>
      <parent link="lower_arm_link"/>
      <child link="wrist_link"/>
      <axis xyz="0 0 1"/>
      <limit effort="10" velocity="10" lower="-1.65806" upper="1.65806"/>
    </joint>
    <joint name="wrist_roll" type="revolute">
      <origin xyz="5.55112e-17 -0.0611 0.0181" rpy="1.5708 0.0486795 3.14159"/>
      <parent link="wrist_link"/>
      <child link="wrist_roll_link"/>
      <axis xyz="0 0 1"/>
      <limit effort="10" velocity="10" lower="-2.74385" upper="2.84121"/>
    </joint>
  </xacro:macro>
</robot>

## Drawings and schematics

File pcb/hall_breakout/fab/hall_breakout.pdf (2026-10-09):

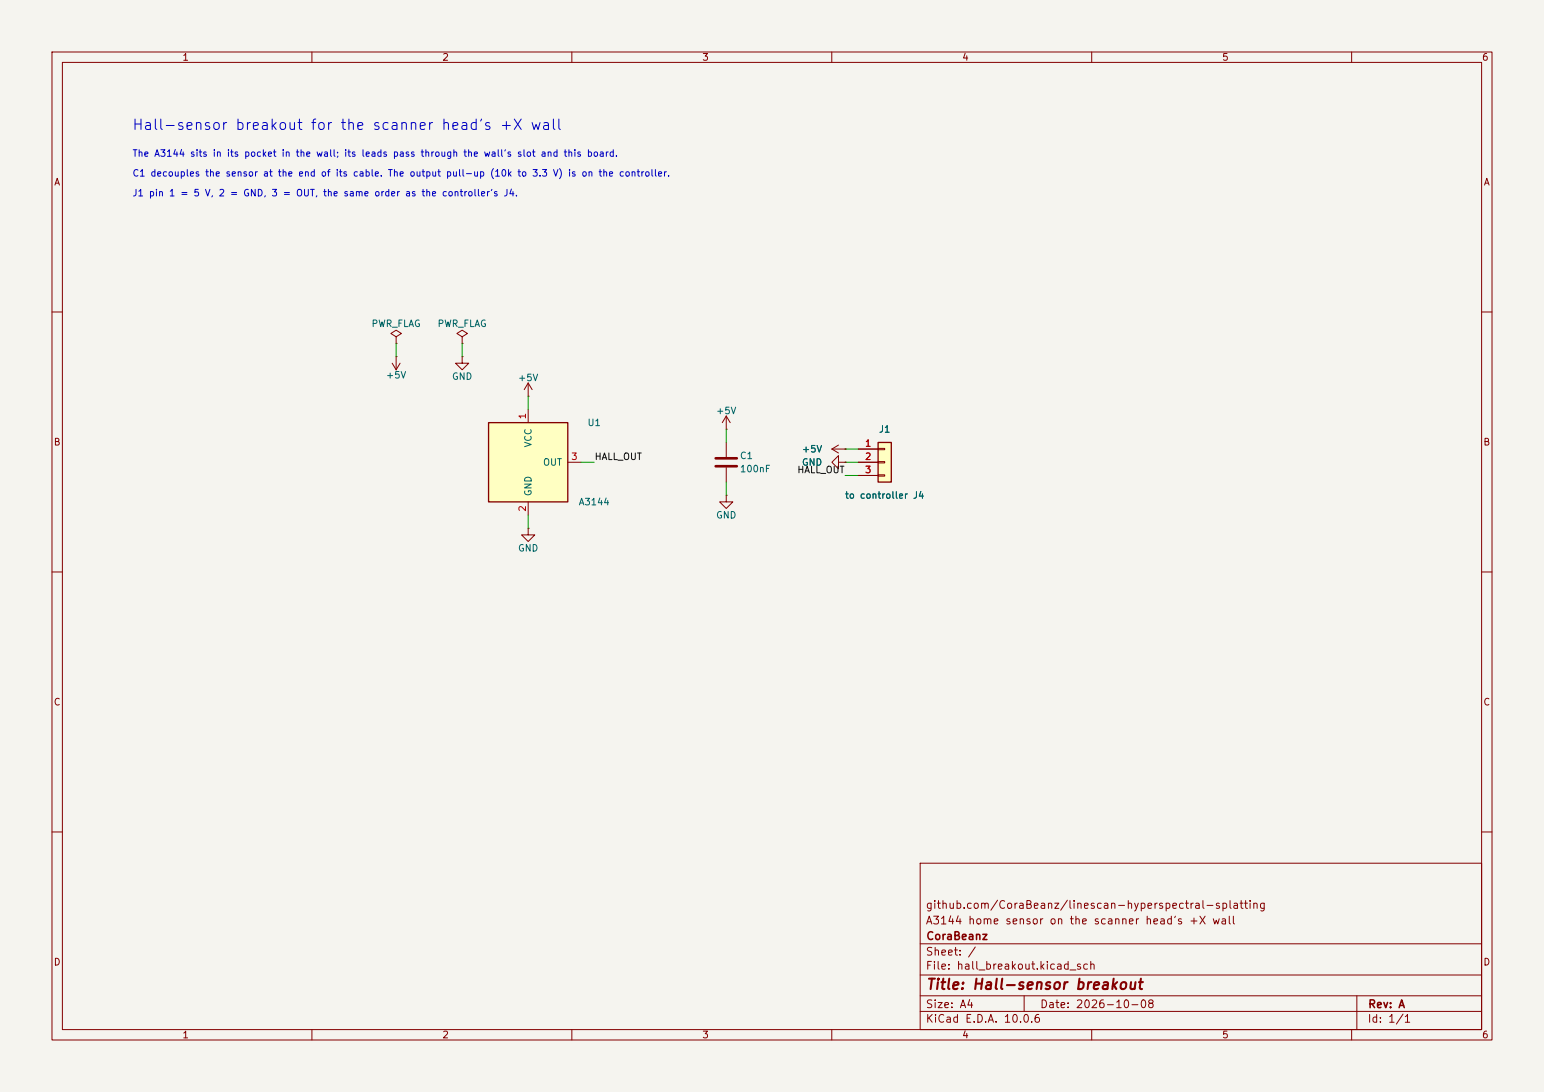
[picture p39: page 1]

github.com/CoraBeanz/linescan-hyperspectral-splatting
A3144 home sensor on the scanner head's +X wall
CoraBeanz
Sheet: /
File: hall_breakout.kicad_sch
Title: Hall-sensor breakout

Size: A4 | Rev: A
KiCad E.D.A. 10.0.6 | Id: 1/1

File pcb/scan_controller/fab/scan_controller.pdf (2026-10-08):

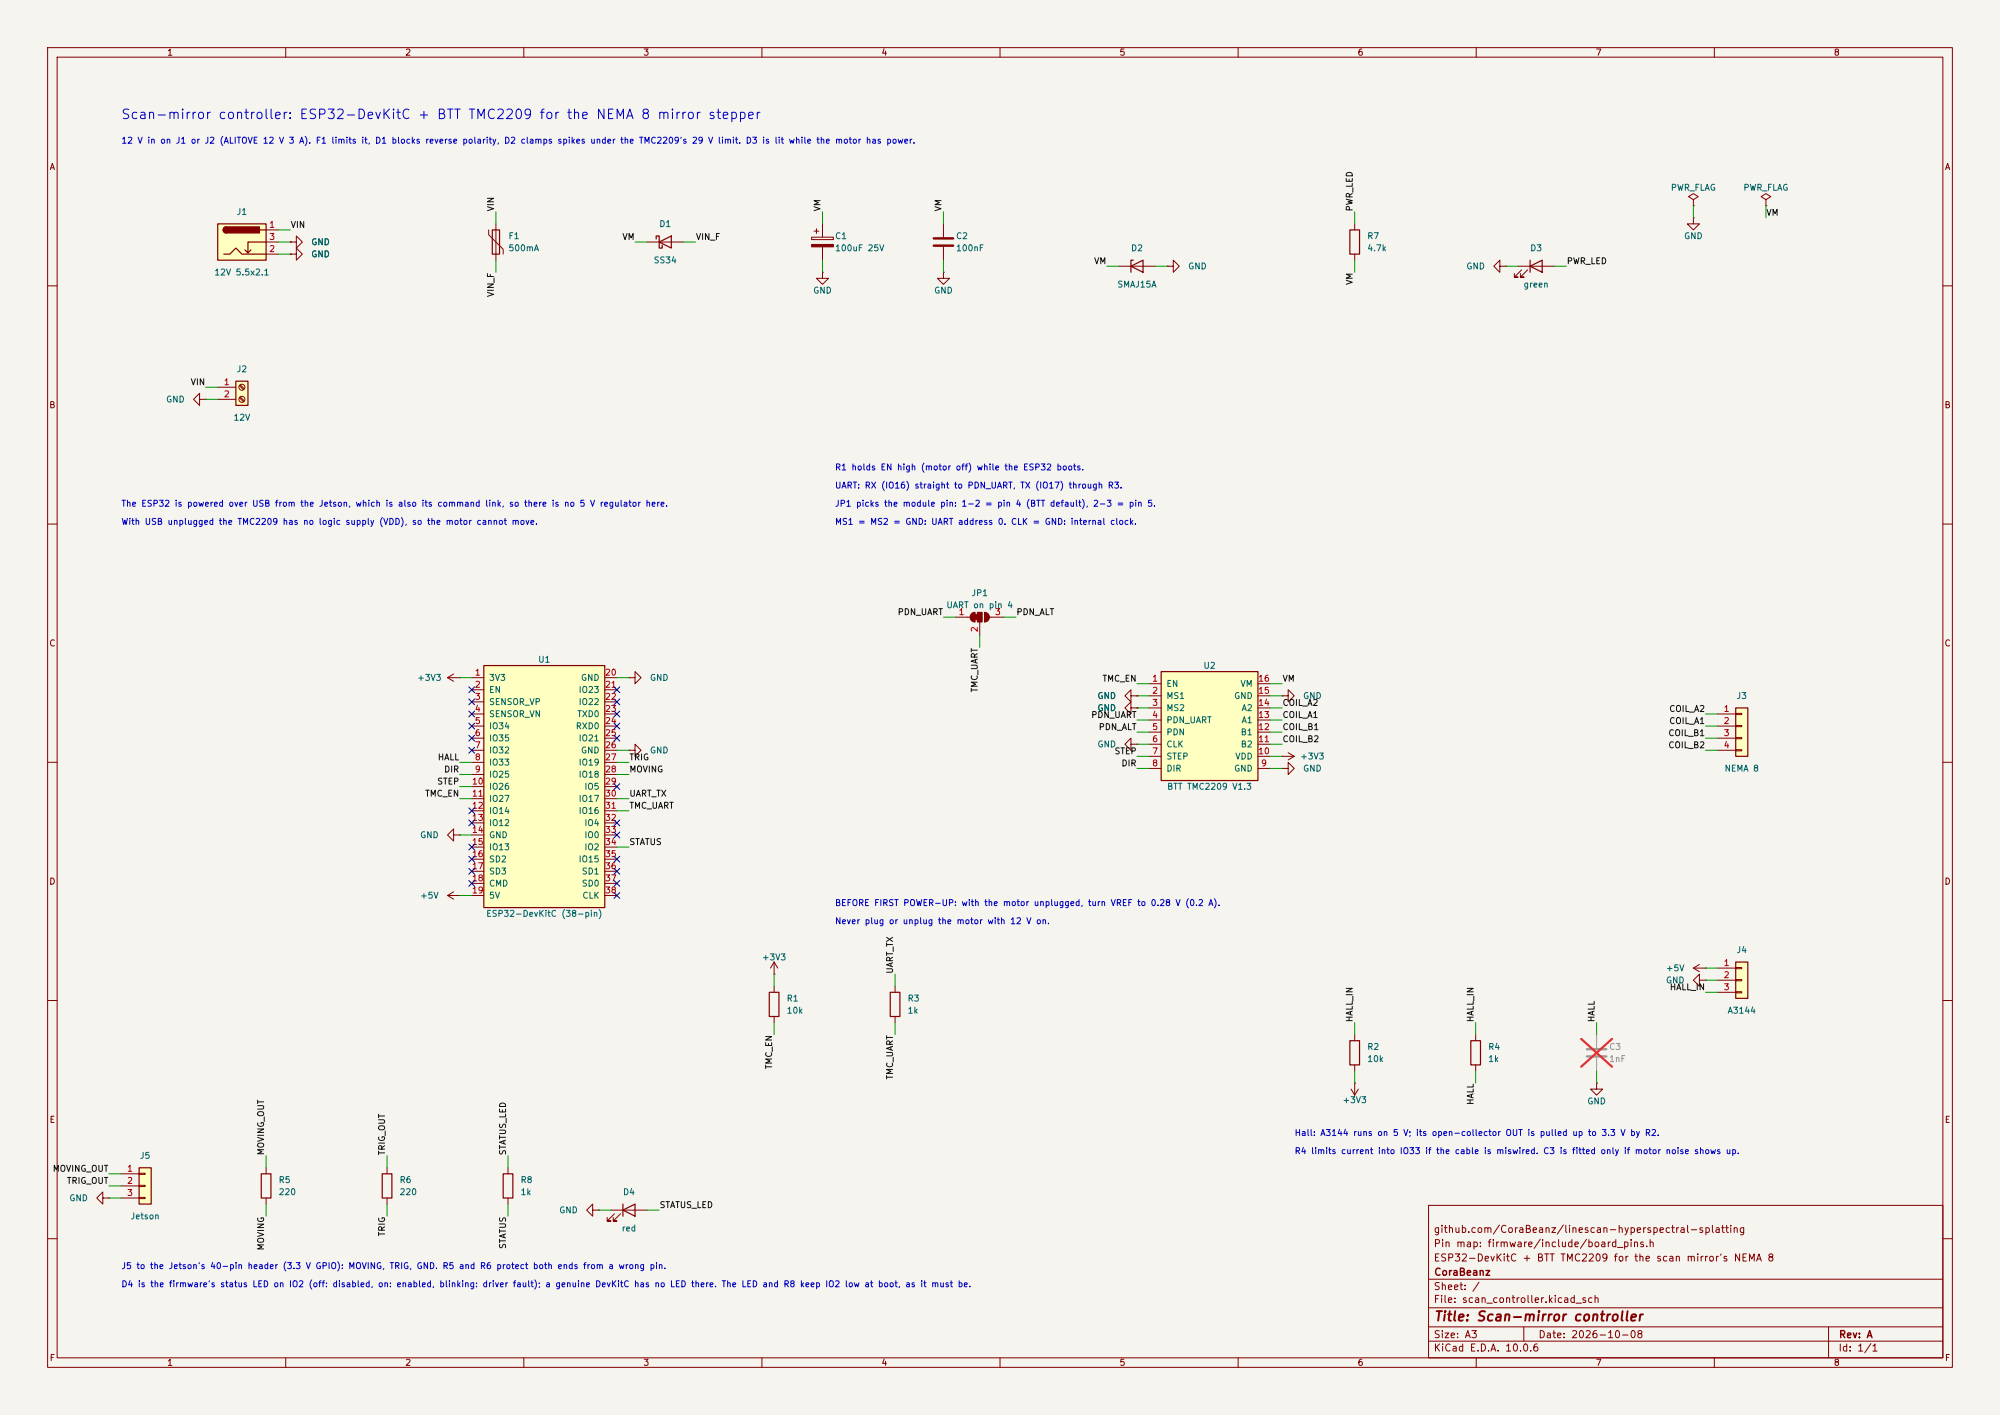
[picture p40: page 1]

12 V in on J1 or J2 (ALITOVE 12 V 3 A). F1 limits it, D1 blocks reverse polarity, D2 clamps spikes under the TMC2209's 29 V limit. D3 is lit while the motor has power.

JP1 picks the module pin: 1-2 = pin 4 (BTT default), 2-3 = pin 5.

github.com/CoraBeanz/linescan-hyperspectral-splatting +3V3

R4 limits current into IO33 if the cable is miswired. C3 is fitted only if motor noise shows up.

Pin map: firmware/include/board_pins.h
ESP32-DevKitC + BTT TMC2209 for the scan mirror's NEMA 8
CoraBeanz
Sheet: /
File: scan_controller.kicad_sch
Title: Scan-mirror controller

J5 to the Jetson's 40-pin header (3.3 V GPIO): MOVING, TRIG, GND. R5 and R6 protect both ends from a wrong pin.

D4 is the firmware's status LED on IO2 (off: disabled, on: enabled, blinking: driver fault); a genuine DevKitC has no LED there. The LED and R8 keep IO2 low at boot, as it must be.

Size: A3 | Rev: A | F Date: 2026-10-08
KiCad E.D.A. 10.0.6 | Id: 1/1

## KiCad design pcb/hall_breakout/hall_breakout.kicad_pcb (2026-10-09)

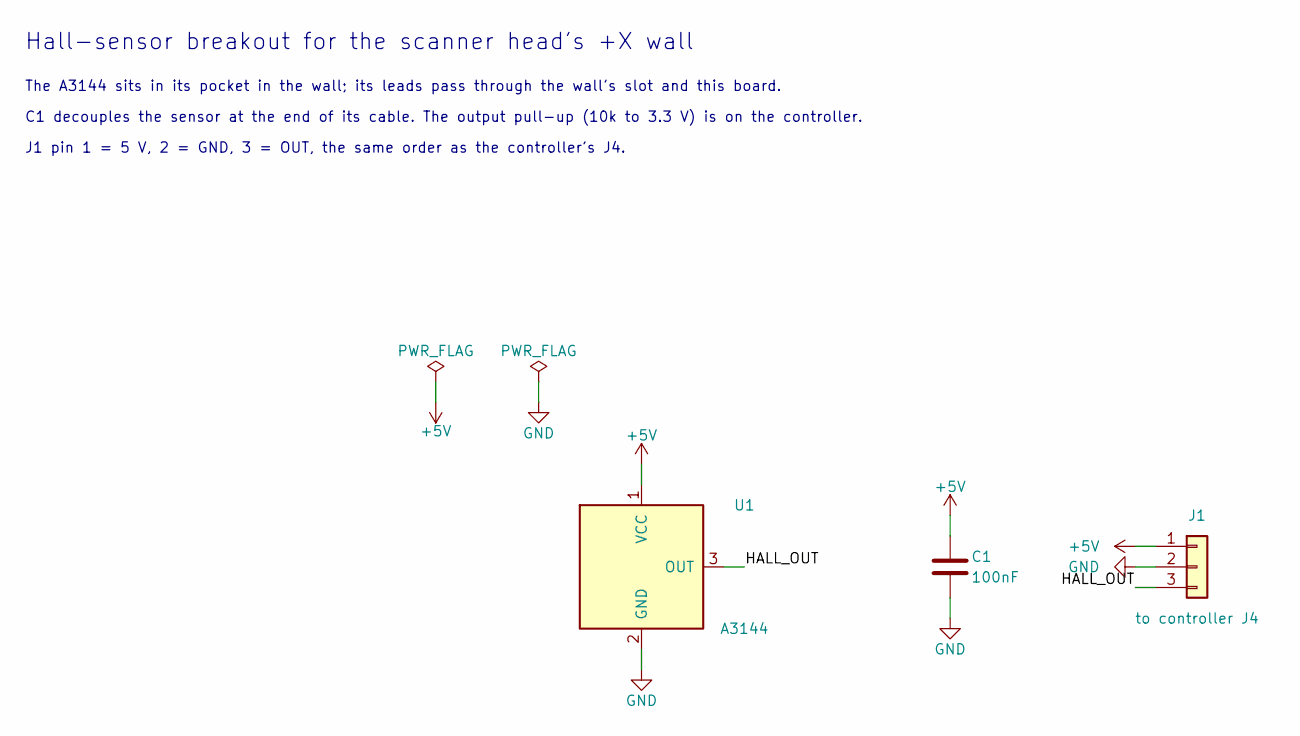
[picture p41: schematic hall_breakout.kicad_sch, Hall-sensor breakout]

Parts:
C1: 100nF; C_0805_2012Metric_Pad1.18x1.45mm_HandSolder; MPN YAGEO CC0805KRX7R9BB104; LCSC C49678
J1: to controller J4; Wire_Pads_1x03_P2.54mm; MPN 3-wire cable soldered in (or a 1x3 pin 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
U1: A3144; A3144_UA_Leads; MPN Allegro A3144 (Gikfun), UA package

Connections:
+5V: C1.1, J1.1, U1.1 (VCC)
/HALL_OUT: J1.3, U1.3 (OUT)
GND: C1.2, J1.2, U1.2 (GND)

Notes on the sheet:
C1 decouples the sensor at the end of its cable. The output pull-up (10k to 3.3 V) is on the controller.
The A3144 sits in its pocket in the wall; its leads pass through the wall's slot and this board.
Hall-sensor breakout for the scanner head's +X wall
J1 pin 1 = 5 V, 2 = GND, 3 = OUT, the same order as the controller's J4.

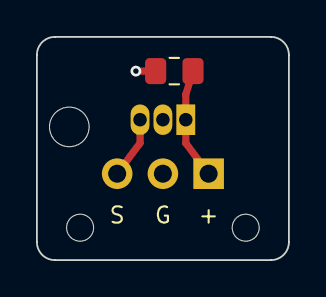
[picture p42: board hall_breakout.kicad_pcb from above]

Board: 2 copper layers, 14.0 x 12.4 mm, 6 parts (0 on the bottom side), 3 nets.

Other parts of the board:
H1: M2; Hole_M2_2.2mm
H2, H3: tie; Hole_NPTH_1.5mm

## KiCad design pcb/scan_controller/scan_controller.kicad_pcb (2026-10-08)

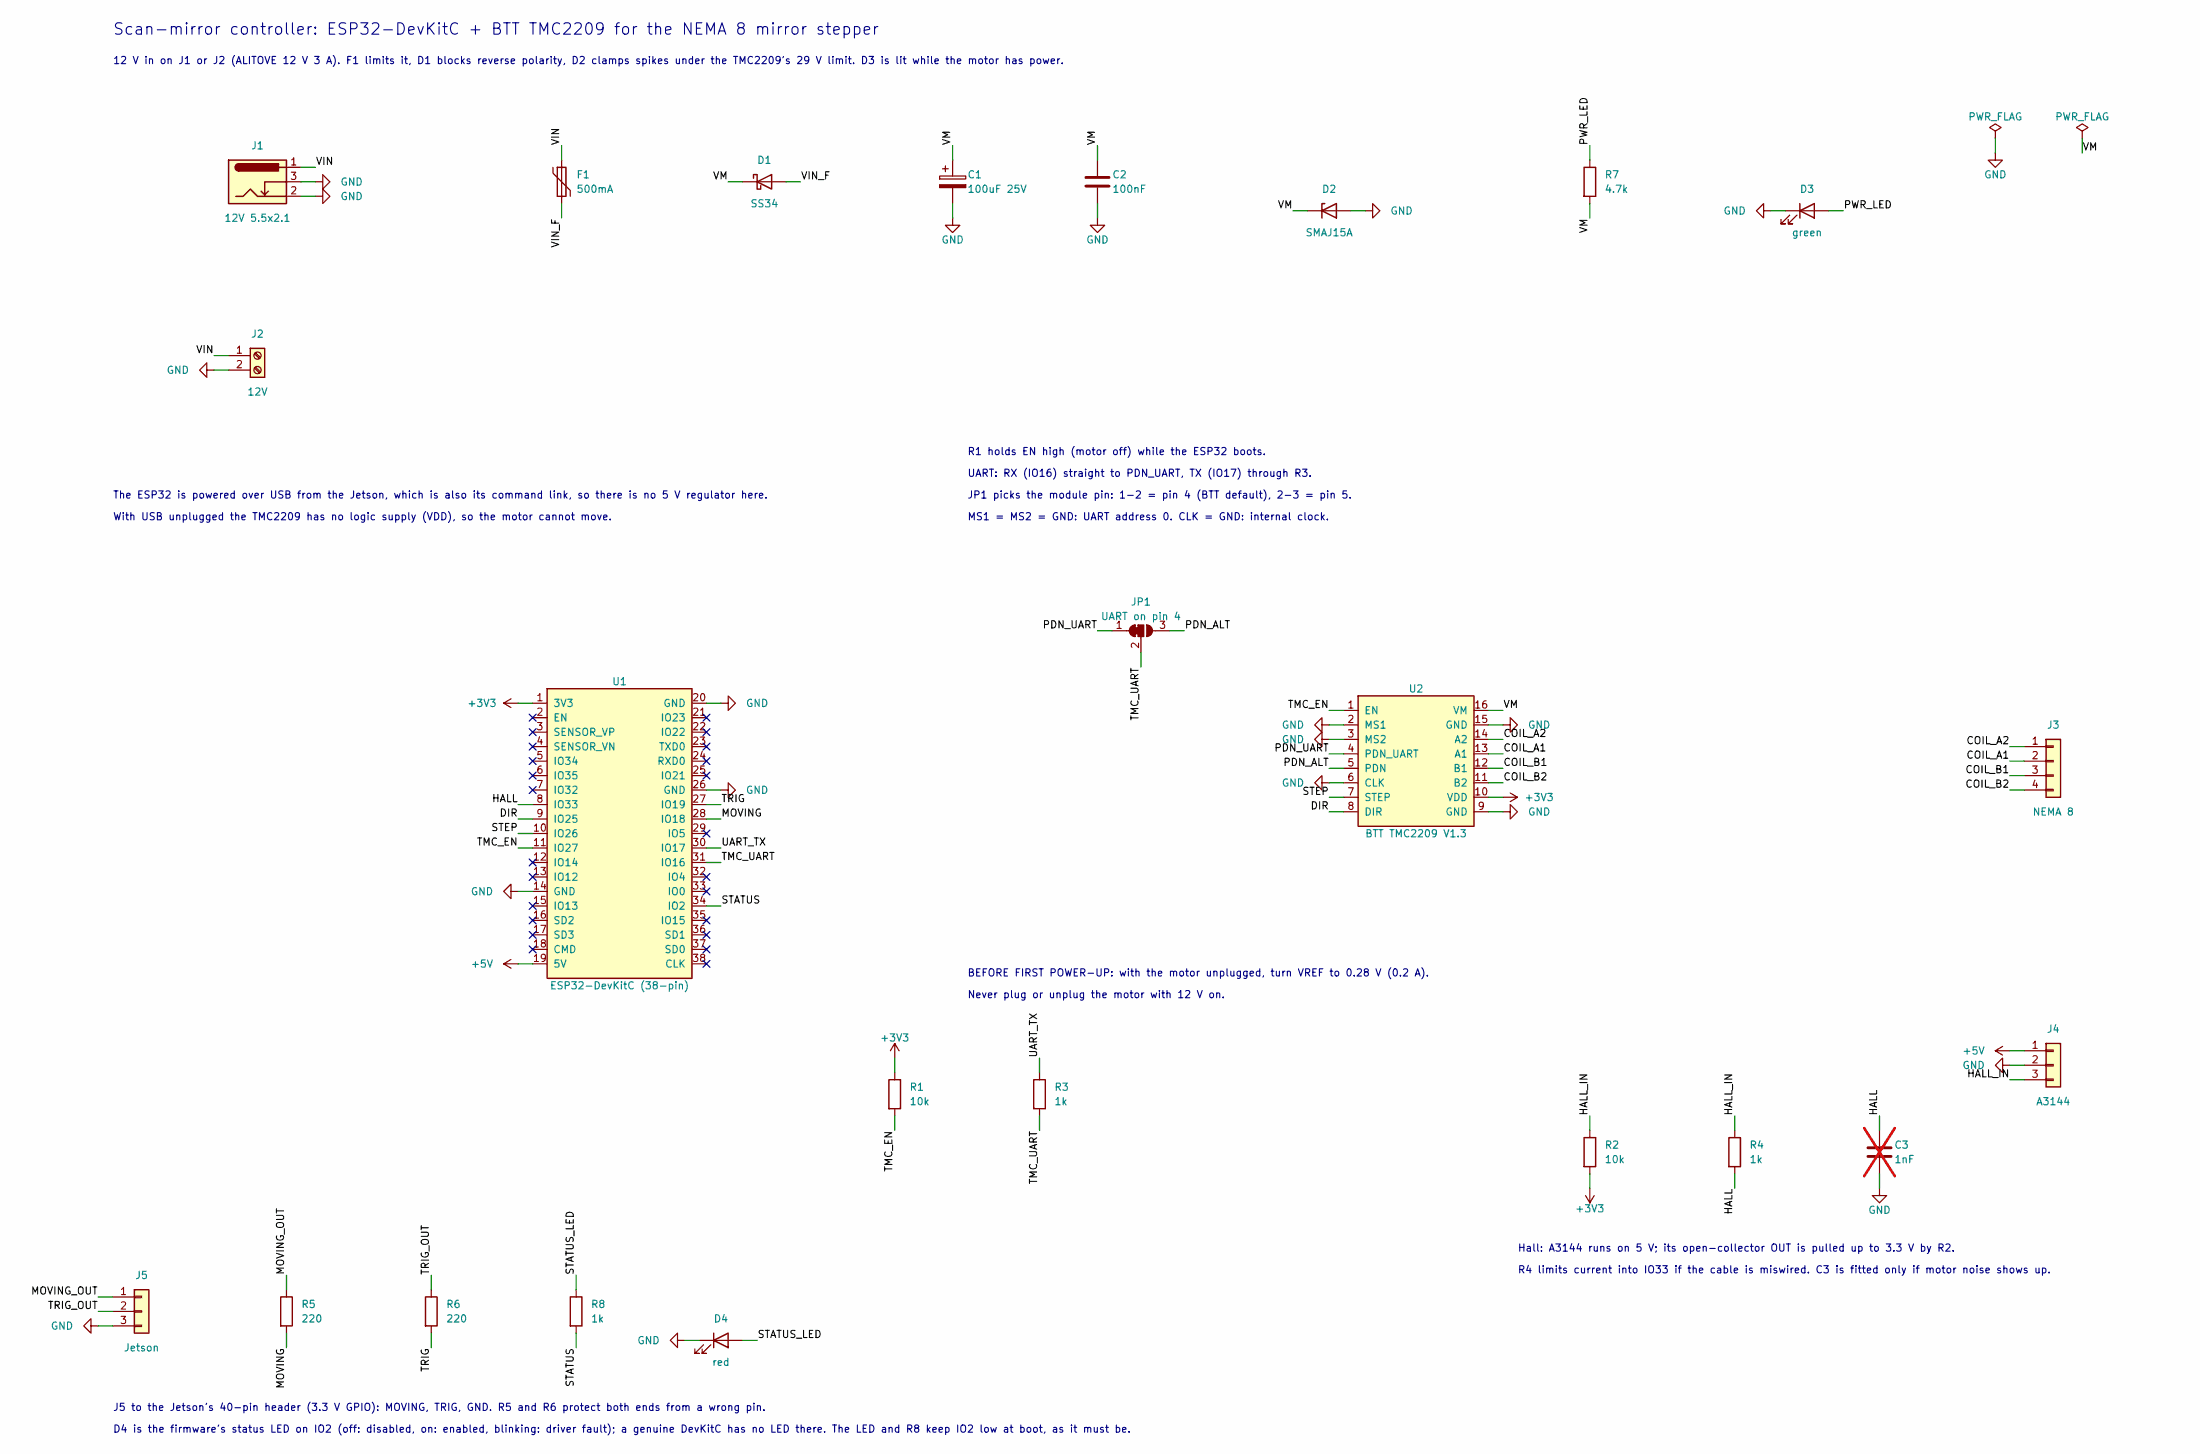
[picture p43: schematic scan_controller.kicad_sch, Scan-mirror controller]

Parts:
C1: 100uF 25V; CP_Radial_D6.3mm_P2.50mm; MPN 100 uF 25 V or 35 V electrolytic, 6.3 m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
C2: 100nF; C_0805_2012Metric; MPN YAGEO CC0805KRX7R9BB104; LCSC C49678
C3: 1nF; C_0805_2012Metric; MPN Samsung CL21B102KBCNNNC; LCSC C46653; not fitted
D1: SS34; D_SMA; MPN MDD SS34; LCSC C8678
D2: SMAJ15A; D_SMA; MPN MDD SMAJ15A; LCSC C113958
D3: green; LED_0805_2012Metric; MPN Hubei KENTO KT-0805G; LCSC C2297
D4: red; LED_0805_2012Metric; MPN NATIONSTAR NCD0805R1; LCSC C84256
F1: 500mA; Fuse_1812_4532Metric; MPN PTTC SMD1812P050TF/30; LCSC C492015
J1: 12V 5.5x2.1; BarrelJack_Horizontal; MPN DC-005 style 5.5 x 2.1 mm jack, 3 pins
J2: 12V; TerminalBlock_Phoenix_MKDS-1,5-2-5.08_1x02_P5.08mm_Horizont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; MPN 2-pin screw terminal, 5.08 mm (KF301-5.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
J3: NEMA 8; JST_XH_B4B-XH-A_1x04_P2.50mm_Vertical; MPN JST B4B-XH-A(LF)(SN); LCSC C144395
J4: A3144; JST_XH_B3B-XH-A_1x03_P2.50mm_Vertical; MPN JST B3B-XH-A(LF)(SN); LCSC C144394
J5: Jetson; PinHeader_1x03_P2.54mm_Vertical; MPN 1x3 pin header, 2.54 mm
JP1: UART on pin 4; SolderJumper-3_P1.3mm_Bridged12_RoundedPad1.0x1.5mm_NumberL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
R1, R2: 10k; R_0805_2012Metric; MPN UNI-ROYAL 0805W8F1002T5E; LCSC C17414
R3, R4, R8: 1k; R_0805_2012Metric; MPN UNI-ROYAL 0805W8F1001T5E; LCSC C17513
R5, R6: 220; R_0805_2012Metric; MPN UNI-ROYAL 0805W8F2200T5E; LCSC C17557
R7: 4.7k; R_0805_2012Metric; MPN UNI-ROYAL 0805W8F4701T5E; LCSC C17673
U1: ESP32-DevKitC (38-pin); ESP32-DevKitC_Socket; MPN 2x female header 1x19, 2.54 mm (ESP32-D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
U2: BTT TMC2209 V1.3; StepStick_Socket_BTT_TMC2209; MPN 2x female header 1x8, 2.54 mm (driver p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

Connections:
+3V3: R1.1, R2.2, U1.1 (3V3), U2.10 (VDD)
+5V: J4.1, U1.19 (5V)
/COIL_A1: J3.2, U2.13 (A1)
/COIL_A2: J3.1, U2.14 (A2)
/COIL_B1: J3.3, U2.12 (B1)
/COIL_B2: J3.4, U2.11 (B2)
/DIR: U1.9 (IO25), U2.8 (DIR)
/HALL: C3.1, R4.2, U1.8 (IO33)
/HALL_IN: J4.3, R2.1, R4.1
/MOVING: R5.2, U1.28 (IO18)
/MOVING_OUT: J5.1, R5.1
/PDN_ALT: JP1.3 (B), U2.5 (PDN)
/PDN_UART: JP1.1 (A), U2.4 (PDN_UART)
/PWR_LED: D3.2 (A), R7.1
/STATUS: R8.2, U1.34 (IO2)
/STATUS_LED: D4.2 (A), R8.1
/STEP: U1.10 (IO26), U2.7 (STEP)
/TMC_EN: R1.2, U1.11 (IO27), U2.1 (EN)
/TMC_UART: JP1.2 (C), R3.2, U1.31 (IO16)
/TRIG: R6.2, U1.27 (IO19)
/TRIG_OUT: J5.2, R6.1
/UART_TX: R3.1, U1.30 (IO17)
/VIN: F1.1, J1.1, J2.1
/VIN_F: D1.2 (A), F1.2
/VM: C1.1, C2.1, D1.1 (K), D2.1 (K), R7.2, U2.16 (VM)
GND: C1.2, C2.2, C3.2, D2.2 (A), D3.1 (K), D4.1 (K), J1.2, J1.3, J2.2, J4.2, J5.3, U1.14 (GND), U1.20 (GND), U1.26 (GND), U2.2 (MS1), U2.3 (MS2), U2.6 (CLK), U2.9 (GND), U2.15 (GND)

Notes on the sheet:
J5 to the Jetson's 40-pin header (3.3 V GPIO): MOVING, TRIG, GND. R5 and R6 protect both ends from a wrong pin.
JP1 picks the module pin: 1-2 = pin 4 (BTT default), 2-3 = pin 5.
12 V in on J1 or J2 (ALITOVE 12 V 3 A). F1 limits it, D1 blocks reverse polarity, D2 clamps spikes under the TMC2209's 29 V limit. D3 is lit while the motor has power.
D4 is the firmware's status LED on IO2 (off: disabled, on: enabled, blinking: driver fault); a genuine DevKitC has no LED there. The LED and R8 keep IO2 low at boot, as it must be.
The ESP32 is powered over USB from the Jetson, which is also its command link, so there is no 5 V regulator here.
With USB unplugged the TMC2209 has no logic supply (VDD), so the motor cannot move.
BEFORE FIRST POWER-UP: with the motor unplugged, turn VREF to 0.28 V (0.2 A).
MS1 = MS2 = GND: UART address 0. CLK = GND: internal clock.
Never plug or unplug the motor with 12 V on.
Scan-mirror controller: ESP32-DevKitC + BTT TMC2209 for the NEMA 8 mirror stepper
UART: RX (IO16) straight to PDN_UART, TX (IO17) through R3.
R4 limits current into IO33 if the cable is miswired. C3 is fitted only if motor noise shows up.
Hall: A3144 runs on 5 V; its open-collector OUT is pulled up to 3.3 V by R2.
R1 holds EN high (motor off) while the ESP32 boots.

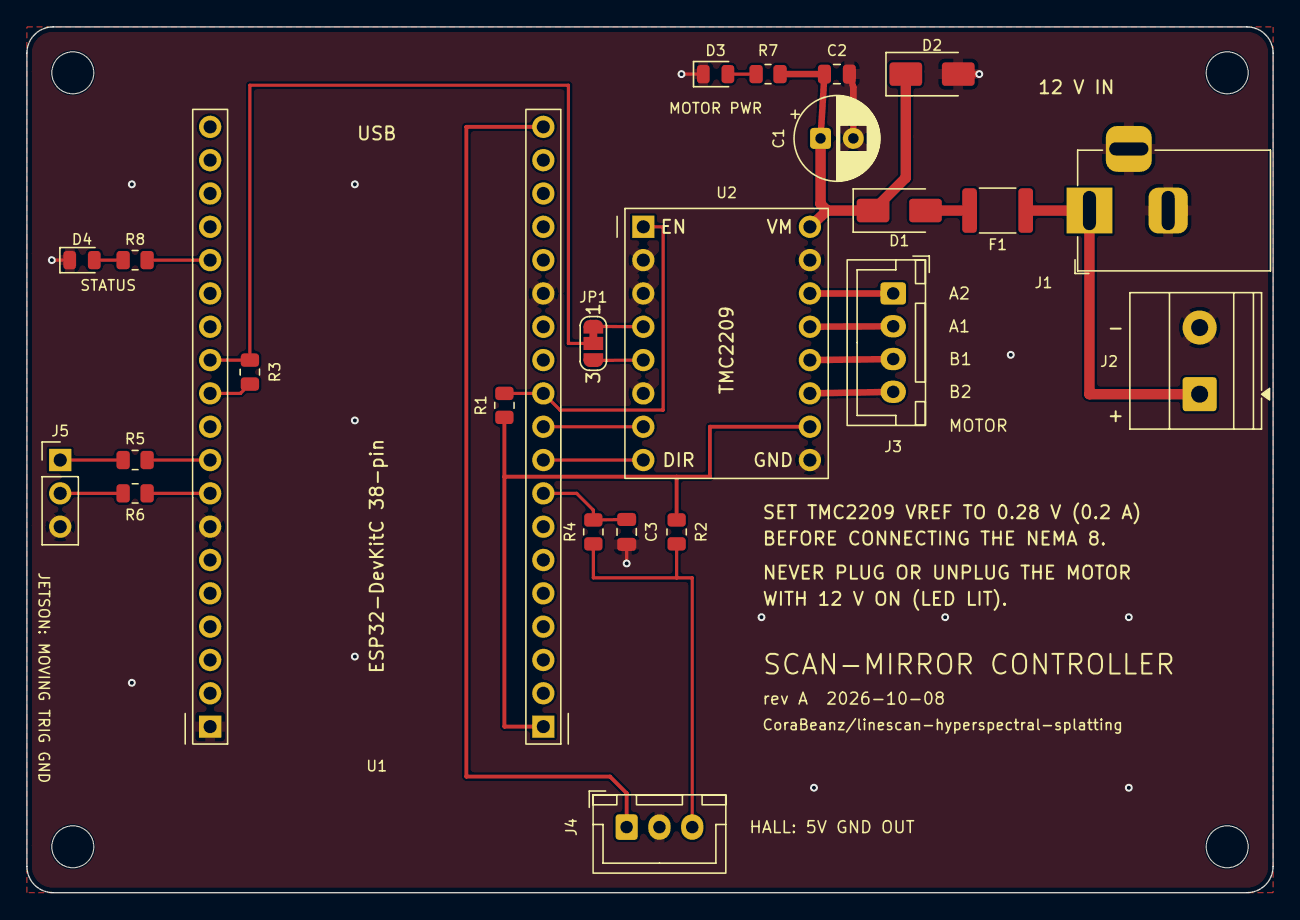
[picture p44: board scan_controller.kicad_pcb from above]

Board: 2 copper layers, 95.0 x 66.0 mm, 28 parts (0 on the bottom side), 26 nets.

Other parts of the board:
H1, H2, H3, H4: M3; MountingHole_3.2mm_M3

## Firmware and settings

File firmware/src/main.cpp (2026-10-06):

// ESP32 side of the scan-mirror firmware: the 50 us timer interrupt that
// steps the motor, the TMC2209 on UART2, settings in flash and the USB serial
// link to the host. Everything that decides what to do lives in
// lib/scanmirror, which the native tests run on a simulated rig.
#include <Arduino.h>
#include <Preferences.h>
#include <TMCStepper.h>
#include <esp_rom_sys.h>
#include <esp_system.h>
#include <esp_timer.h>
#include <soc/gpio_struct.h>

#include "board_pins.h"
#include "sm_controller.h"
#include "sm_core.h"

namespace {

static_assert(kPinStep < 32 && kPinDir < 32 && kPinMoving < 32 && kPinTrig < 32,
              "the interrupt drives its outputs through the GPIO 0-31 registers");

sm::MirrorCore g_core;
// Guards g_core between the interrupt (core 0) and loop() (core 1).
portMUX_TYPE g_mux = portMUX_INITIALIZER_UNLOCKED;
volatile bool g_dir_invert = false;
volatile bool g_timer_running = false;

// Where SAVE keeps the settings in flash (NVS).
constexpr char kPrefsNamespace[] = "scanmirror";
constexpr char kPrefsKey[] = "cfg";

inline void IRAM_ATTR setPin(uint8_t pin, bool high) {
  if (high) {
    GPIO.out_w1ts = 1u << pin;
  } else {
    GPIO.out_w1tc = 1u << pin;
  }
}

inline bool IRAM_ATTR readPin(uint8_t pin) {
  return pin < 32 ? ((GPIO.in >> pin) & 1u) != 0 : ((GPIO.in1.data >> (pin - 32)) & 1u) != 0;
}

// Every 50 us, on core 0: one MirrorCore tick, then the pins it asks for.
void IRAM_ATTR onTick() {
  static bool dir_level = false;
  const int64_t now = esp_timer_get_time();
  const bool hall = readPin(kPinHall);
  portENTER_CRITICAL_ISR(&g_mux);
  const sm::TickOut out = g_core.tick(now, hall);
  portEXIT_CRITICAL_ISR(&g_mux);

  if (out.step != 0) {
    const bool level = (out.step > 0) != g_dir_invert;
    if (level != dir_level) {
      setPin(kPinDir, level);
      dir_level = level;
      esp_rom_delay_us(1);  // DIR settles before the STEP edge
    }
    setPin(kPinStep, true);
  }
  setPin(kPinMoving, out.moving);
  setPin(kPinTrig, out.trig);
  if (out.step != 0) {
    esp_rom_delay_us(1);  // the TMC2209 needs STEP high for 100 ns or more
    setPin(kPinStep, false);
  }
}

// An interrupt runs on the core that set it up, so set the timer up from a
// short-lived task on core 0. loop() runs on core 1, so serial traffic and
// the TMC2209's UART waits never delay a step.
void timerSetupTask(void*) {
  hw_timer_t* timer = timerBegin(0, 80, true);  // 80 MHz APB clock / 80: 1 us per count
  timerAttachInterrupt(timer, &onTick, false);
  timerAlarmWrite(timer, sm::kTickUs, true);
  timerAlarmEnable(timer);
  g_timer_running = true;
  vTaskDelete(nullptr);
}

const char* resetReason() {
  switch (esp_reset_reason()) {
    case ESP_RST_POWERON: return "poweron";
    case ESP_RST_EXT: return "external";
    case ESP_RST_SW: return "software";
    case ESP_RST_PANIC: return "panic";
    case ESP_RST_INT_WDT: return "int_wdt";
    case ESP_RST_TASK_WDT: return "task_wdt";
    case ESP_RST_WDT: return "wdt";
    case ESP_RST_DEEPSLEEP: return "deepsleep";
    case ESP_RST_BROWNOUT: return "brownout";
    case ESP_RST_SDIO: return "sdio";
    default: return "unknown";
  }
}

// ---------------------------------------------------------------- board

class EspPort : public sm::Port {
 public:
  int64_t nowUs() override { return esp_timer_get_time(); }
  void lock() override { portENTER_CRITICAL(&g_mux); }
  void unlock() override { portEXIT_CRITICAL(&g_mux); }

  void writeLine(const char* s, size_t n) override {
    Serial.write(reinterpret_cast<const uint8_t*>(s), n);
    Serial.write('\n');
  }

  bool saveConfig(const sm::Config& c) override {
    Preferences prefs;
    if (!prefs.begin(kPrefsNamespace, false)) return false;
    const bool ok = prefs.putBytes(kPrefsKey, &c, sizeof(c)) == sizeof(c);
    prefs.end();
    return ok;
  }

  bool loadConfig(sm::Config* c) override {
    Preferences prefs;
    if (!prefs.begin(kPrefsNamespace, true)) return false;  // nothing saved yet
    const bool ok = prefs.getBytesLength(kPrefsKey) == sizeof(*c) &&
                    prefs.getBytes(kPrefsKey, c, sizeof(*c)) == sizeof(*c);
    prefs.end();
    return ok;
  }

  void setDirInvert(bool invert) override { g_dir_invert = invert; }

  void reboot() override {
    Serial.flush();
    delay(20);
    ESP.restart();
  }
};

// The TMC2209 over its single-wire UART. TMCStepper waits a few ms for each
// register, which only ever holds up loop(), never the step interrupt.
class Tmc2209 : public sm::Driver {
 public:
  Tmc2209() : tmc_(&Serial2, kTmcRSense, kTmcAddress) {}

  bool configure(const sm::Config& c) override {
    if (tmc_.version() != 0x21 || tmc_.CRCerror) return false;  // nobody there, or not a TMC2209
    tmc_.GSTAT(0);                 // clear the reset and error flags
    tmc_.begin();                  // PDN_UART is the UART; microsteps come from MRES
    tmc_.I_scale_analog(false);    // current from IRUN/IHOLD, not from the VREF pot
    tmc_.en_spreadCycle(c.stealth == 0);
    tmc_.TPWMTHRS(0);              // when in StealthChop, stay in it at every speed
    tmc_.toff(3);
    tmc_.blank_time(24);
    tmc_.intpol(true);             // smooth each microstep into 256
    tmc_.mres(mres(c.usteps));
    tmc_.iholddelay(8);            // ease down to the hold current
    tmc_.TPOWERDOWN(20);           // after 0.44 s at standstill
    tmc_.rms_current(static_cast<uint16_t>(c.irun), c.ihold / 100.0f);

    // Writes are not acknowledged, so read two registers back.
    const uint32_t gconf = tmc_.GCONF();
    if (tmc_.CRCerror) return false;
    const uint32_t chopconf = tmc_.CHOPCONF();
    if (tmc_.CRCerror) return false;
    // GCONF: I_scale_analog (bit 0) off, en_SpreadCycle (bit 2) as asked,
    // pdn_disable (bit 6) and mstep_reg_select (bit 7) on.
    const uint32_t want_gconf = 0xC0u | (c.stealth == 0 ? 0x04u : 0u);
    return (gconf & 0xC5u) == want_gconf && ((chopconf >> 24) & 0xFu) == mres(c.usteps);
  }

  bool setFullHold(bool full, const sm::Config& c) override {
    tmc_.rms_current(static_cast<uint16_t>(c.irun), full ? 1.0f : c.ihold / 100.0f);
    return true;  // writes are not acknowledged
  }

  bool read(sm::DriverStatus* s) override {
    s->gstat = tmc_.GSTAT();
    if (tmc_.CRCerror) return false;
    if (s->gstat != 0) tmc_.GSTAT(0);  // write-1-to-clear
    s->drv_status = tmc_.DRV_STATUS();
    if (tmc_.CRCerror) return false;
    s->ioin = tmc_.IOIN();
    if (tmc_.CRCerror) return false;
    s->mscnt = tmc_.MSCNT();
    return !tmc_.CRCerror;
  }

  void enable(bool on) override { digitalWrite(kPinEn, on ? LOW : HIGH); }

 private:
  // MRES: 0 = 256 microsteps per full step ... 8 = full steps.
  static uint8_t mres(int32_t usteps) {
    uint8_t m = 8;
    while (usteps > 1 && m > 0) {
      usteps >>= 1;
      --m;
    }
    return m;
  }

  TMC2209Stepper tmc_;
};

EspPort g_port;
Tmc2209 g_driver;
sm::Controller g_ctl(g_core, g_port, g_driver);

// ---------------------------------------------------------------- serial input

constexpr size_t kMaxLine = 255;
char g_line[kMaxLine + 1];
size_t g_line_len = 0;
bool g_line_overflow = false;

// Collects one command per line ("\n", "\r" or both end it). Backspace works,
// so a plain serial terminal can drive it too.
void readSerial() {
  for (int budget = 256; budget > 0 && Serial.available() > 0; --budget) {
    const int c = Serial.read();
    if (c < 0) break;
    if (c == '\n' || c == '\r') {
      if (g_line_overflow) {
        static const char kTooLong[] = "ERR ? code=syntax msg=line longer than 255 characters";
        g_port.writeLine(kTooLong, sizeof(kTooLong) - 1);
      } else if (g_line_len > 0) {
        g_line[g_line_len] = '\0';
        g_ctl.handleLine(g_line);
      }
      g_line_len = 0;
      g_line_overflow = false;
    } else if (c == '\b' || c == 0x7F) {
      if (g_line_len > 0) --g_line_len;
    } else if (g_line_len < kMaxLine) {
      g_line[g_line_len++] = static_cast<char>(c);
    } else {
      g_line_overflow = true;
    }
  }
}

// LED: off while disabled, on while enabled, blinking on a driver fault.
void updateLed() {
  static int last = -1;
  const int on = g_ctl.faulted() ? static_cast<int>((millis() / 250) % 2) : g_ctl.enabled() ? 1 : 0;
  if (on != last) {
    digitalWrite(kPinLed, on ? HIGH : LOW);
    last = on;
  }
}

}  // namespace

void setup() {
  // Motor off before anything else.
  digitalWrite(kPinEn, HIGH);
  pinMode(kPinEn, OUTPUT);
  digitalWrite(kPinStep, LOW);
  pinMode(kPinStep, OUTPUT);
  digitalWrite(kPinDir, LOW);
  pinMode(kPinDir, OUTPUT);
  pinMode(kPinMoving, OUTPUT);
  pinMode(kPinTrig, OUTPUT);
  pinMode(kPinLed, OUTPUT);
  pinMode(kPinHall, INPUT_PULLUP);

  Serial.setRxBufferSize(1024);
  Serial.begin(kHostBaud);
  Serial2.begin(kTmcBaud, SERIAL_8N1, kPinTmcRx, kPinTmcTx);

  // Settings and the driver first, so the first tick already uses them.
  g_ctl.begin(resetReason());
  xTaskCreatePinnedToCore(timerSetupTask, "tick_setup", 4096, nullptr, 5, nullptr, 0);
  while (!g_timer_running) delay(1);
}

void loop() {
  readSerial();
  g_ctl.poll();
  updateLed();
}

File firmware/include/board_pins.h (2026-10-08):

// Pin map for an ESP32 DevKit (esp32dev) wired to a BIGTREETECH TMC2209
// module. The wiring table in firmware/README.md follows this file.
#pragma once

#include <stdint.h>

// TMC2209 step/dir inputs. EN is active low: the motor is powered only while
// it is low. Fit a 10k pull-up from EN to 3.3 V so the motor stays off while
// the ESP32 boots and its pins float.
constexpr uint8_t kPinStep = 26;
constexpr uint8_t kPinDir = 25;
constexpr uint8_t kPinEn = 27;

// TMC2209 single-wire UART on PDN_UART: RX straight to the pin, TX through a
// 1k resistor (the TMC2209 and the ESP32 take turns driving the one wire).
constexpr uint8_t kPinTmcRx = 16;
constexpr uint8_t kPinTmcTx = 17;
constexpr uint32_t kTmcBaud = 115200;
constexpr uint8_t kTmcAddress = 0;  // MS1 and MS2 low
constexpr float kTmcRSense = 0.11f;  // BTT TMC2209 sense resistors, ohms

// A3144 hall switch, open collector: low when the magnet is at the sensor.
// The internal pull-up is weak for a cable up the arm; add 10k to 3.3 V.
constexpr uint8_t kPinHall = 33;

// Timing outputs for a scope, logic analyser or the Jetson's GPIO (3.3 V).
constexpr uint8_t kPinMoving = 18;  // high while the mirror moves or settles
constexpr uint8_t kPinTrig = 19;    // short pulse when a scan line is ready

// Status LED. A genuine ESP32-DevKitC has no LED on GPIO 2 (clones often have
// a blue one); the scan controller board (pcb/) has its own here, D4.
constexpr uint8_t kPinLed = 2;

// USB serial link to the host.
constexpr uint32_t kHostBaud = 921600;

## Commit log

2026-10-05 Fix README description of the spectrograph optical train
    The README said the 16 mm objective collimates the slit and the 25 mm
    lens refocuses onto the camera. In the design, the objective images the
    scene onto the slit, the 25 mm lens collimates the slit, and the camera's
    own 12 mm lens refocuses the spectrum. Also describes the field lens and
    the M12 IMX219 NoIR camera from the v2 design.
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2026-10-06 Redesign the README around diagrams and Optiland figures
    The README now opens with an animated hero banner and a one-line pitch,
    then shows the rig, the optical path and the Optiland results before
    the prose, with links to the design doc, the model, the parts list, the
    SO-101 and LeRobot pages and the splatting papers.
    New images in docs/img/: the hero, a diagram of the arm with the
    scanner head, an optical path schematic for config C, and three figures
    traced from the Optiland model (dispersion plane, field-lens comparison,
    simulated sensor frames). optics/readme_figures.py renders the PNGs from
    spectrograph_model.py; docs/img/src/ holds the scripts that draw the SVGs.
    The SO-101 photo is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
2026-10-06 Add FreeCAD model of the SO-101 with the scanner head
    cad/build_rig.py builds a parametric FreeCAD assembly from a Params
    spreadsheet: the SO-101 follower from TheRobotStudio's URDF, the
    spectrograph head with every bought part on the layout C optical axis,
    and printable housing, lid, optics carriers, mirror clamp, filter cap
    and wrist puck.
    Each build checks part overlaps, the mirror's full turn, wrist roll and
    flex clearance, and the servo load, then exports the printed parts as
    STL in print orientation, the head as STEP and a JSON report.
    optics_check.py traces the as-built spacings with the Optiland model.
    The README covers print settings, hardware, assembly and what is
    estimated; rende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
    [bench_puck.stl, filter_cap.stl, grating_carrier.stl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]
2026-10-06 Add a NEMA 8 scan stepper as a build option
    RIG_MOTOR=8HS11 builds the head with an 8HS11-0204S (NEMA 8, 60 g)
    instead of the 17HM08-1204S pancake. The housing and optics stay where
    they are. The lid gets a smaller motor pad with four M2 counterbores,
    the two long bolts end in washers and nuts on that pad, and the mirror
    clamp follows the shorter shaft.
    The head drops from 281 g to 188 g, and the worst-case shoulder load
    from 94% to 75% of stall. Every check passes for both motors. The
    default build is unchanged apart from the stepper's label.
    [hsi_head.step, so101_hsi_rig.FCStd]
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2026-10-06 Make the NEMA 8 the default scan stepper
    The head now carries an 8HS11-0204S (NEMA 8, 1.8 deg, 60 g) instead of
    the 17HM08-1204S pancake, which stays available as RIG_MOTOR=17HM08.
    The head drops from 281 g to 188 g, and with the arm stretched out
    level the shoulder servo needs 75% of its stall torque instead of 94%.
    Every check still passes.
    Only the lid and mirror clamp STLs change. The renders, report, STEP
    and CAD README follow the new default, and the top-level README and
    its two diagrams now name the NEMA 8 with 1/32 microstepping.
    [hsi_head.step, lid.stl, mirror_clamp.stl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]
2026-10-06 Show the CAD renders in the README
    A new CAD model section under The rig shows the rendered arm and head
    and the labelled cut-away, with a short summary of what the model
    checks. The nav bar links to it instead of the bare cad/ folder.
2026-10-06 Fit the head to the Edmund mirror, filter and field lens
    The shopping list now buys the scan mirror, long-pass filter and field
    lens from Edmund, and the printed parts were drawn for other sizes.
    - Mirror clamp: the pad and magnet tab end at a fixed pad_x1, so the
    20 x 20 x 3 mm mirror (#43-872) or anything up to 25 mm long fits
    with the magnet still at the hall sensor. Notches in the pad's edges
    mark where the mirror's ends go.
    - The 3 mm glass puts the mirror face 1 mm further from the shaft. The
    shaft and the long lid bolts stay where they were (y_shaft is now the
    input), so the optical axis moves 0.7 mm toward the scene; the -Y
    interior grows to match and the full-turn sweep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
    [filter_cap.stl, grating_carrier.stl, housing.stl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]
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2026-10-06 Pass /Zc:preprocessor to MSVC when compiling the CUDA rasterizer
    CUDA 13's Thrust and CUB headers stop with an #error when cl.exe uses its
    traditional preprocessor, so the Windows build failed on rasterizer.cu.
    Hand cl.exe the standard-conforming one through nvcc's -Xcompiler, only
    when MSVC is the host compiler; the Jetson's gcc build doesn't change.
    Built and tested on TheRig: VS 2026 (MSVC 19.51), CUDA 13.4, RTX 4070 SUPER.
2026-10-06 Add the scan mirror bridge, sweep logger and viewpoint planner
    so101_scan_sweep holds the scanning side:
    - scan_mirror_bridge talks to the mirror ESP32 over a plain-text serial
    protocol (mirror_protocol.py), turns microsteps into mirror angles,
    publishes the mirror joint and one ScanLine per line, and offers home,
    move, start_sweep and stop services. It maps the ESP32's microsecond
    clock onto ROS time from ping round trips, so each line is stamped with
    the ROS time the mirror settled.
    - fake_scan_mirror is a simulated ESP32 on a pseudo-terminal, with a
    drifting clock and USB-like delays, for running without hardware.
    - scan_sweep runs a scan plan: it moves the arm to each viewpo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
    [plan.py]
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2026-10-06 Copy GPU renders straight into the result and time the GPU work
    On TheRig the rasterizer's passes took about 2.6 ms for the default
    synthetic scan, but render() took 53 ms: it zero-filled two 80 MB host
    buffers on every call and unpadded the channels one pixel at a time.
    The raster kernel now writes the scene's K channels instead of the
    padded count, so each batch downloads straight into the image, and a
    new render(cams, &image) overload reuses an image of the right size
    without clearing it. CudaRenderStats gains gpu_ms, timed with CUDA
    events around the passes, and splat_render compare reports both times.
    Also replace thrust::plus, deprecated in CUDA 13, with a small functor
    that CUDA 10.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
2026-10-06 Add the TheRig GPU timings and Windows build notes to the splat README
    The CUDA renderer does the default dataset in 2.8 ms of GPU work on an
    RTX 4070 SUPER (9.3 ms with the copy back), and the Windows build is
    tested with Visual Studio 2026 and CUDA 13.4. A mirror homing offset is
    absorbed by the per-sweep head pose, so the text no longer promises a
    separate mirror parameter.
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2026-10-06 Stop the arm and mirror on Ctrl-C, and end a scan when a move fails
    Ctrl-C in scan_sweep now cancels the arm's move, tells the mirror to stop,
    and still writes scan.json; in move_arm it stops the arm where it is. A
    move that fails (the arm blocked, or the servo bus lost) ends the scan
    instead of sweeping at the wrong pose.
    Scans default to $SO101_SCAN_DATA/scans, which the Docker setup mounts
    from the host, rather than a home folder inside the container.
    The stack test now covers both Ctrl-C cases and runs the fake servo bus
    in its own process.
    [plan.py]
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2026-10-06 Recover the mirror bridge from an ESP32 reset, a lost SCAN_DONE and an unplug
    - Find the message in a line the boot ROM's garbage is glued to, so EV BOOT
    after a reset is seen; if it is lost anyway, the ESP32's clock going back
    in a PING or STATUS reply gives the reset away.
    - End the sweep when STATUS shows the ESP32 stopped scanning but its
    SCAN_DONE never arrived, so the next sweep isn't refused forever.
    - Guard the serial port with the write lock, so a write racing the reader
    thread's close on unplug can't raise.
    - Keep a broken handler from killing the reader thread.
    - hold_until is one 50 us timer step early, as the firmware's tick can be.
    - The fake mirror works its times out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
2026-10-06 Add a spectrometer calibration kit
    calibration/ holds hsical, a Python package that captures raw lamp, flat
    and dark frames on the Jetson and, on a PC, fits the wavelength of every
    pixel from CFL and neon lines, the smile and keystone warp, and the
    spectral response from a halogen lamp on PTFE. It writes a report with
    pass/fail checks and the remap tables a C++/CUDA renderer needs.
    It is tested on synthetic sessions rendered from the Optiland model,
    including a soft-lens case; calibration/README.md has the first-light
    procedure.
    [lines.csv]
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2026-10-06 Add a trainer with per-sweep pose refinement
    Trainer fits a GaussianScene to a dataset's lines with Adam, starting from
    Gaussians on the board plane, and densifies and prunes per (line, Gaussian)
    pair. It also refines one 6-DoF head pose per sweep, carrying each line
    camera's gradient back to a correction made in the camera's frame; no sweep
    is pinned, since that bakes its error into the whole scene.
    splat_train trains on a dataset and, for synthetic data, reports how far the
    line cameras are from the true ones before and after. splat_synth gains
    --errors to scale the pose errors, and the sweep previews move into the
    library so both tools can write them.
2026-10-06 Describe training in the splat README
    How the trainer works and why (board-plane start, per-line densification,
    one pose correction per sweep, no pinned sweep), results on the synthetic
    scans with 6 to 16 sweeps, a figure of trained scenes next to the truth,
    what limits the pose accuracy, splat_train usage, and new next steps.
2026-10-06 Share the CPU backward pass's zeroing and summing across threads
    Each thread sums its lines' gradients into its own copy, and every copy
    was zeroed and then added up on one thread. With 28 threads on TheRig
    that was tens of MB per step, and CPU training ran faster on 8 threads
    than on 28. Now each thread zeroes its own copy, the copies are summed
    in parallel over the Gaussians (skipping the ones a copy never drew),
    and every thread gets at least four lines. On a 4-core machine asked
    for 28 threads, a step at 13,600 Gaussians goes from 33 ms to 22 ms
    (on 4 threads, from 18 ms to 17 ms).
2026-10-06 Match parts list to the Edmund optics the CAD head uses
    Field lens #49-840 (12.7 mm, f = 15 mm), GG-495 long-pass #54-652
    (12.5 x 3 mm) and 20 x 20 x 3 mm mirror #43-872 replace #32-008, the
    37 mm screw-in filter and #43-792. The slit, holder and fastener rows
    point at the parts the head is drawn for, the design text notes the
    as-built grating and camera spacing, and the totals move to about
    $1,200 recommended and $525 budget.
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2026-10-06 Keep replaced moves and stretched sweeps inside the soft limits
    A MOVE sent while the mirror was moving braked at its own acceleration,
    so a gentler MOVE replacing a fast one could carry the mirror far past
    max: 2336 microsteps at a=20000 after a v=10000 a=1000000 move, and 76
    turns at a=100. The step generator now brakes at the hardest
    acceleration, and stops from the highest start speed, of any move since
    the mirror was last at rest, so braking never runs past an earlier
    target.
    NUDGE or PERIOD could stretch a sweep past the range SCAN checked.
    Sweeps now run with min or max as a limit: the mirror stops on it and
    the scan ends with aborted=1.
    DRV clears GSTAT when it reads it, which hid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
2026-10-07 Build splat for the Jetson Nano in a JetPack 4.6 container
    jetson/Dockerfile is the build image: L4T r32.7.1 (Ubuntu 18.04) with gcc 7.5,
    CMake 3.28 from pip and nlohmann/json 3.11. CUDA isn't in it: on JetPack 4 the
    NVIDIA runtime mounts the Nano's own CUDA 10.2 into containers started with
    --runtime nvidia, so jetson/splat.sh compiles splat for sm_53 and runs its
    tests and tools with docker run, as the calling user, with the groups that own
    the GPU's device nodes. With the GPU expected, a CUDA test that skips for want
    of a device fails the run.
    jetson/check.sh builds the same image and runs the same script on a PC, twice:
    from Ubuntu 18.04 with CUDA 10.2 and gcc 7.5 (the toolkit copied ou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
2026-10-07 Build the ROS 2 image on JetPack 4.6's Docker
    Ubuntu 22.04 starts threads and processes with clone3, which Docker's seccomp
    profile refuses before 20.10.10, and JetPack 4.6 has 20.10.7. run.sh already
    runs its containers without the filter, but docker build can't drop it, so
    the image's first apt-get update fails (reproduced on a 20.10.7 daemon, with
    both of its builders).
    jetson/ros.sh checks Docker's version and, below 20.10.10, builds the same
    Dockerfile with a current BuildKit in a privileged container, whose own
    profile answers clone3 with ENOSYS so glibc falls back to clone, and loads the
    result with docker load. On a newer Docker it's a plain docker build. Then it
    hands over to ros2/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
2026-10-07 Add the Nano's setup, a day-one build script and the jetson runbook
    nano_setup.sh does the one-time host setup: checks for L4T r32 and Docker's
    NVIDIA runtime, adds the user to the docker group, adds a 4 GB swap file and
    installs the USB port rules. build_all.sh builds and tests splat and the ROS 2
    packages, and runs a small synthetic dataset and 300 training steps on the
    GPU. jetson/README.md has the commands and how it all works.
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2026-10-07 Add the software to the README
    A Software section with a diagram of how the modules connect, a table of
    what CI checks with a status badge per workflow, and short sections on
    the firmware (with a frame-sync timing diagram), the ROS 2 side, the
    calibration kit, the simulator and the Jetson build. Reconstruction gets
    the synthetic training results and the viewer. The ESP32 talks
    plain-text serial, not micro-ROS, so the rig section, the rig diagram,
    the stack table and the parts list say so, and the head's mass and
    servo load follow the refitted CAD model (185 g, 74%).
2026-10-07 Lock mirror sweeps to the spectrograph camera's frames
    The camera's frames come on their own 30 fps clock, so a sweep on the mirror's
    clock lets some exposures catch the mirror moving. While line_camera publishes
    FrameStamps, scan_mirror_bridge fits the frame clock and plans each sweep on it:
    the line period becomes a whole number of frames, long enough for the move and
    settle between two exposures, and the first tick is placed so every move falls
    in the gap. During the sweep it follows the camera's drift with NUDGE (phase)
    and PERIOD (rate) on the firmware's protocol, one adjustment at a time.
    StartSweep reports the period used, whether it is locked and the frames per
    line. The fake ESP32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
2026-10-07 Test the camera through the whole stack and document scanning with it
    test_capture_stack brings up scan_arm.launch.py with camera:=fake, takes a white
    with capture_reference, runs a plan that requires the camera and converts the
    scan: the sweep is locked at one frame a line, every line is recorded and
    binned, and scan_to_dataset finds the white through scan.json.
    scan.json keeps line_camera's reference folder under camera.references, so it
    doesn't clash with the simulator's calibration_session (an hsical session);
    the converter resolves both relative to the scan folder and takes the white's
    reflectance from its meta.json. line_camera remembers its reference folder
    across restarts.
    ros2/REA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
2026-10-08 Join the executor's thread before scan_sweep and move_arm exit
    scan_sweep sometimes aborted after a good scan with "terminate called
    without an active exception" (exit 250 through ros2 run), which failed
    test_scan_stack at random. Its executor spins in a daemon thread that
    was never joined: when Python shut down while that thread was still in
    rclpy's C++ wait, the C++ runtime aborted. Both mains now join the thread
    after executor.shutdown(). A minimal copy of the exit path aborted in 54
    of 60 runs without the join and in none of 60 with it.
2026-10-08 Host the viewer and a front page on GitHub Pages
    The viewer was only reachable by cloning the repo and serving it. A pages
    workflow now builds a small site with docs/site/build.sh: a front page in
    the viewer's colours (the hero, how it works, a way into the viewer), and
    the viewer with its two sample splats under viewer/. docs/site/check.mjs
    opens it in headless Chromium, as Pages serves it, before main deploys it.
    Until Pages is switched on in the repository settings, the deploy is
    skipped with a warning instead of failing. The READMEs link the live
    viewer, and the CI table gets the workflow's badge.
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2026-10-08 Add KiCad boards for the scan-mirror controller and hall sensor
    Two boards in a new pcb/ directory, drawn in KiCad 10:
    - scan_controller: ESP32-DevKitC (38-pin) and BTT TMC2209 in sockets,
    wired to firmware/include/board_pins.h, with a protected 12 V input
    (PTC fuse, reverse-polarity Schottky, TVS, bulk capacitance), JST XH
    connectors for the NEMA 8 and the hall sensor, and a 3-pin header for
    the Jetson. 95 x 66 mm, 2 layers.
    - hall_breakout: takes the A3144's leads on the outside of the head's
    +X wall, with a 100 nF bypass capacitor and pads for the cable.
    14 x 12.4 mm, 0.8 mm thick.
    Both pass ERC and DRC with no errors or warnings, including schematic
    parity. fab/ holds the J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
    [bom.csv, bom_jlc.csv, hall_breakout.kicad_pcb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]
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2026-10-08 Plan views around an object and dry-run plans without moving the arm
    make_plan --object X Y [Z] --size W D H plans for coverage: it tries
    views from several tilts and azimuths aimed where they meet the box,
    works out which points on its top and sides each sweep sees in focus
    and facing the camera, and keeps the fewest views that see every point
    twice, in an order that keeps the moves short.
    scan_sweep --dry-run plays a plan on the running stack without sending
    anything to the arm or the mirror: a see-through arm moves through the
    viewpoints on /scan/markers, each sweep's lines appear where they would
    land, and a coverage plan's surface turns green as views see it. It
    checks the moves for jo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
2026-10-08 Wait for the fake mirror to catch up before saying where it was
    The simulated camera in test_camera_node asks the fake ESP32 where the
    mirror was during each exposure. On a busy machine the fake's scan
    thread can wake late for a line tick that has already passed, and until
    it records that line's move, pos_at_wall answered with the line before.
    The camera then rendered the previous line's scene inside the new
    line's hold, and test_sweeps_record_every_line_cleanly failed about one
    run in three on main. pos_at_wall now waits until the scan has recorded
    every move up to the time asked about.
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2026-10-08 Let the URDF take a measured head geometry
    scan_head.xacro gets a head_calibration argument: empty keeps the CAD
    model's numbers, and a head_calibration.yaml replaces the origins of the
    mount, the mirror shaft, the objective, the folded line camera and the
    pose camera, and the scan line's length. scan_arm.launch.py passes
    $SO101_SCAN_DATA/head_calibration.yaml when it exists (head_calibration:=none
    forces the CAD) and logs which geometry it built. The description tests
    check that no file gives the CAD URDF unchanged and that a calibrated head
    still keeps the line camera the objective's mirror image at every angle.
    [scan_head.xacro, so101_scan.urdf.xacro]
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2026-10-08 Stop the arm on servo faults, stalls and e-stops, and keep it inside soft limits
    The STS3215 driver now checks the arm every control cycle. Load, temperature and supply
    voltage have a warning level and a limit that must hold for a moment before it counts; a
    joint far from its goal and not moving is a stall; the servos' own alarm bits count after two
    reads. Any of these, or an e-stop, holds the arm where it is and ignores the controller; if
    the cause is still there 5 s later the motors go off. A reset waits until the controller asks
    for the pose the arm is in, so a stale goal can't move it.
    Before each goal goes to the servos it is put through the URDF: the head's collision box and
    the arm's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
    [so101_scan.ros2_control.xacro]
2026-10-08 Add arm_estop and check_plan, and stop scans and the mirror when the arm stops
    so101_scan_safety has the tools around the driver's safety checks: arm_estop (a keyboard
    e-stop, and a reset that restarts arm_controller so it starts from where the arm is),
    check_plan (a plan's viewpoints and the moves between them against the same soft limits, in
    Python, from the same numbers in the URDF) and a watcher for /arm_safety/state.
    scan_sweep and move_arm check the plan from where the arm is before moving it, refuse while
    the arm is stopped, and when it stops mid-run cancel the move, stop the mirror, write what was
    logged and exit saying why. The mirror bridge sends the ESP32 a STOP when the arm stop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
    [model.py]
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2026-10-08 Add a status LED to the controller and correct the PCB notes
    A review of the merged boards against the real parts found:
    - The firmware's status LED on GPIO 2 doesn't exist on a genuine
    ESP32-DevKitC, so the controller now has one: D4 (red) through R8
    (1 k) to GND, which also keeps the strapping pin low at boot.
    - The 12 V terminal's + and - marks sat under its plastic body; they
    are now beside it.
    - The A3144's leads leave the bottom of its body, so they run below
    the head wall's current lead slot. The README now gives the hall
    board's position for leads bent under the body and the CAD change
    the slot needs.
    - README: exclude WROVER DevKitCs (GPIO 16/17 are their PSRAM), give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
    [bom.csv, bom_jlc.csv, hall_breakout.kicad_pcb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]
2026-10-08 Fix the firmware docs' status-LED and coil-label notes
    A genuine ESP32-DevKitC has no LED on GPIO 2; the controller board now has its own status LED there. BTT's TMC2209 modules label the coil pins A2, A1, B1, B2, not 1A 1B and 2A 2B.
    [board_pins.h]
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2026-10-08 Route the A3144's leads out of its bottom face and lower the hall breakout
    The A3144 (UA package) has its leads on its bottom face, not its back. In
    the model they now bend 90 degrees just under the body and run out through
    a slot under the pocket, 2.2 mm below the sensor's centre (z 21.2), and the
    pocket floor either side of the slot is a ledge for the body. The breakout
    moves 1.2 mm down to follow them, where pcb/README.md now places it
    (z 13.4 to 25.8). The controller's screw terminal is drawn 14 mm tall, to
    its screw tops, as pcb/README.md now gives it.
    Two arm-safety tests quoted the head's depth below the table in one pose
    to 0.1 mm (97.5). The head's collision box is centred on its c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
    [head_dark.stl, head_metal.stl, head_pcb.stl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]
2026-10-08 Simulate the pose camera and headcal's calibration scan
    hsisim can now render headcal's calibration scan of the ChArUco board:
    the tag board on the table (--scene tagboard), the pose camera's stills
    during each sweep (--pose-camera), and a head off its CAD numbers as a
    hand-built one is (--head-errors), whose frames come from the true head
    while lines.csv logs the CAD one. The stills are in the recorder's
    format (pose/camera.json, frames.csv, still_NNNN.npy), and `hsisim bin`
    writes binned/ as line_camera does with a calibration, so `headcal
    solve` runs on a simulated scan as it would on the rig's. truth/ gains
    head.json, head_calibration.yaml, pose_camera.json and stills_true.csv.
    `hsisim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
    [__main__.py, arm.py, binned.py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]
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

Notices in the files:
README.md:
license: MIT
